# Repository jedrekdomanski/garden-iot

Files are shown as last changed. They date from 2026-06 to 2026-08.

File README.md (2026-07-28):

# 🌱 Garden IoT — Automated Irrigation System

An ESP32-based automated garden irrigation system that measures soil moisture, controls a water pump, and streams telemetry to AWS with real-time visualization via Grafana Cloud.

## Motivation

The idea behind this project was simple — being able to travel, go on holidays, or simply leave home for a day or two without worrying that the vegetables and herbs would die. Instead of relying on someone to water the plants or coming back to a dried-out garden, the system takes care of it automatically. It monitors soil moisture around the clock and waters only when needed, while giving full visibility into what's happening remotely through the Grafana dashboard.

The garden is also planned to grow over time — more plants, more zones, more automation. The system is designed with that in mind, making it easy to extend with additional sensors and devices as the garden expands.

## How it works

The ESP32 is a low-cost, low-power microcontroller with built-in WiFi and Bluetooth, widely used in IoT projects. It features a dual-core 240MHz processor, 520KB of RAM, and a deep sleep mode that draws only ~10µA — making it ideal for battery-powered or solar-powered applications. In this project it runs Arduino firmware compiled with PlatformIO and uses its built-in ADC to read the soil moisture sensor.

The ESP32 wakes from deep sleep every hour, measures soil moisture, decides whether to water, reports all events to AWS, then goes back to sleep. The entire active cycle takes only a few seconds, making it extremely power efficient.

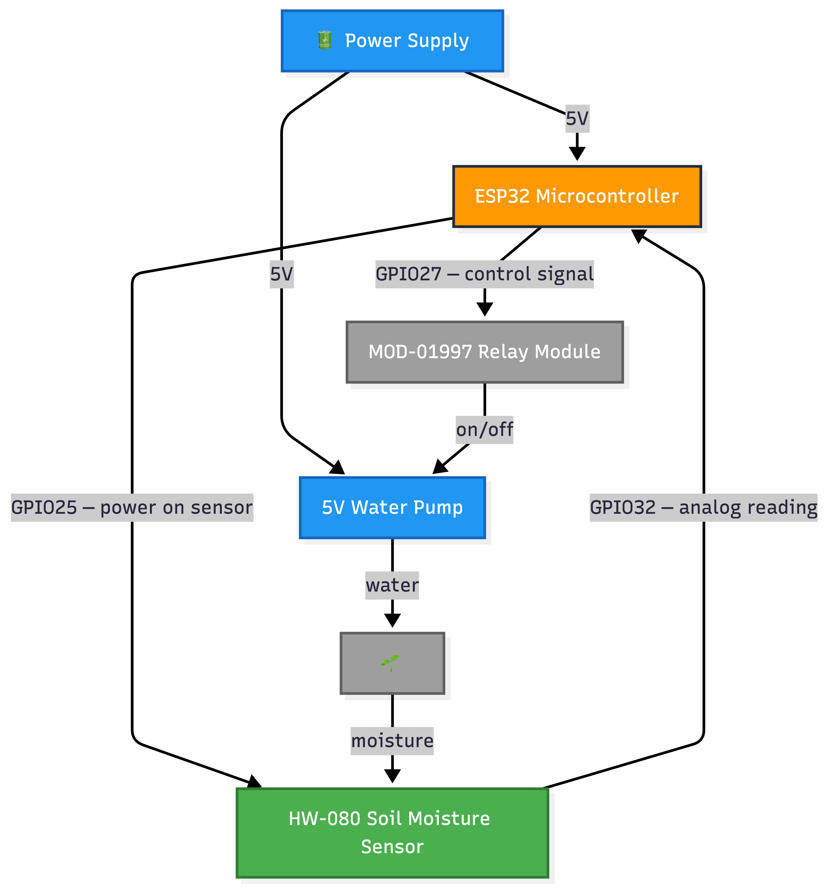
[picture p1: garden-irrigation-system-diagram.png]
Hardware Diagram


### Measurement & watering logic

1. Powers the capacitive soil moisture sensor
2. Takes 10 averaged ADC readings for accuracy
3. Maps the raw value to a 0–100% moisture percentage using calibrated dry/wet values
4. If moisture is below the threshold (60%), triggers the MOSFET transistor to run the water pump for 20 seconds
5. Reports the outcome (`watering_started` / `watering_skipped`) to AWS
6. Goes back to deep sleep for 1 hour

### Events reported

| Event | Description |
|---|---|
| `device_boot` | Device woke up and connected to WiFi |
| `measurement_taken` | Soil moisture reading with raw value and percentage |
| `watering_started` | MOSFET triggered, irrigation started |
| `watering_finished` | MOSFET off, irrigation complete |
| `watering_skipped` | Soil moisture sufficient, watering not needed |
| `device_sleeping` | Device entering deep sleep |

## Hardware

| Component | Details |
|---|---|
| ESP32 DevKit | Dual-core 240MHz, built-in WiFi, deep sleep ~10µA |
| HW-080 Capacitive soil moisture sensor | GPIO 32 (ADC) |
| MOSFET transistor | GPIO 27 — switches power to the water pump |
| Water pump | 12V — controlled via MOSFET transistor |

## AWS Architecture

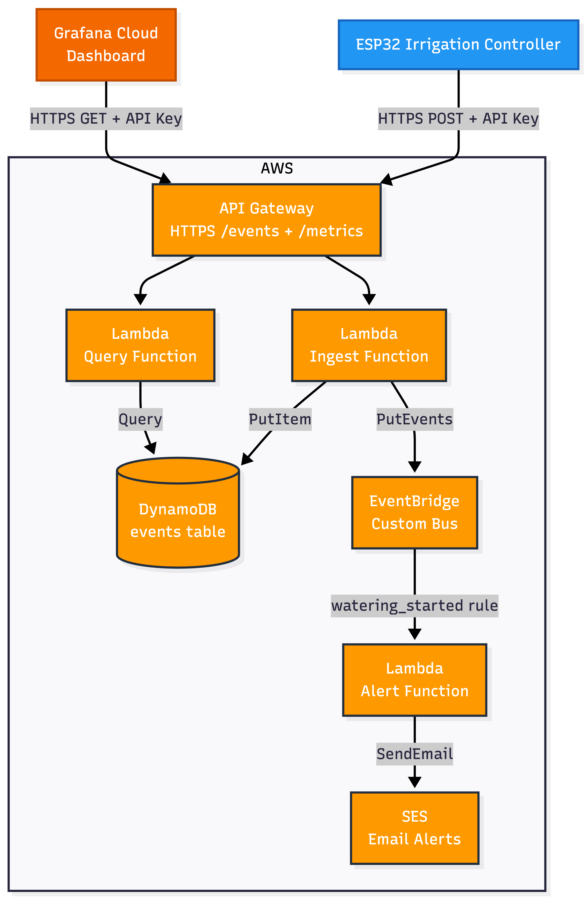
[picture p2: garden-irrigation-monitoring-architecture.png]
System Architecture


### Ingest pipeline
- **API Gateway** — HTTPS endpoint secured with a custom API key authorizer Lambda
- **Ingest Lambda** — validates and writes events to DynamoDB, forwards to EventBridge
- **DynamoDB** — stores all events with a 1-year TTL auto-expiry
- **EventBridge** — routes `measurement_taken` events with moisture < 30% to the alert Lambda
- **SES** — sends email alerts when soil moisture is critically low

### Visualization pipeline
- **Query Lambda** — queries DynamoDB and returns JSON, supports `from`, `to`, and `limit` parameters
- **Grafana Cloud** — polls `GET /metrics` via the Infinity datasource and renders the dashboard

## Grafana Dashboard

Three panels:
- **Current Moisture** — stat panel with color thresholds (green > 45%, yellow > 25%, red below)
- **Soil Moisture** — time series of moisture % over time
- **Event Log** — full table of all device events with timestamps

## Project structure

```
├── firmware/
│   └── garden/
│       ├── src/main.cpp        # ESP32 firmware
│       ├── include/secrets.h   # Generated secrets (git ignored)
│       ├── scripts/load_env.py # Injects .env into build
│       └── platformio.ini
└── terraform/
    ├── lambda/
    │   ├── ingest/handler.py   # Ingest Lambda
    │   ├── query/handler.py    # Query Lambda
    │   ├── authorizer/handler.py
    │   └── alert/handler.py
    ├── api_gateway.tf
    ├── dynamodb.tf
    ├── lambda.tf
    ├── eventbridge.tf
    ├── grafana.tf
    └── ses.tf
```

## Setup

### Prerequisites
- PlatformIO
- Terraform >= 1.6
- AWS CLI with a configured profile
- Grafana Cloud account (free tier)

### Firmware

1. Copy `firmware/.env.example` to `firmware/.env` and fill in your WiFi credentials and API endpoint
2. Build and flash with PlatformIO:
```bash
cd firmware/garden
pio run --target upload
```

### Infrastructure

1. Copy `terraform/terraform.tfvars.example` to `terraform/terraform.tfvars` and set your alert email
2. Deploy:
```bash
cd terraform
terraform init
terraform apply
```
3. Get your API endpoint and key:
```bash
terraform output api_endpoint
terraform output -raw api_key
```

### Grafana Cloud

1. Install the **Infinity** datasource plugin
2. Add a new Infinity datasource with header `x-api-key` set to your API key and allowed host set to your API Gateway domain
3. Create panels using `GET https://<api-endpoint>/metrics` as the data source URL

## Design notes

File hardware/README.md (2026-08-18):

# 🔌 Garden Irrigation System — PCB Hardware

A custom-designed PCB built around the ESP32 DevKit V1, created as part of my personal journey into electronics, IoT, and robotics. The board was designed in **KiCad 10** after several weeks of self-taught KiCad and electronics study.

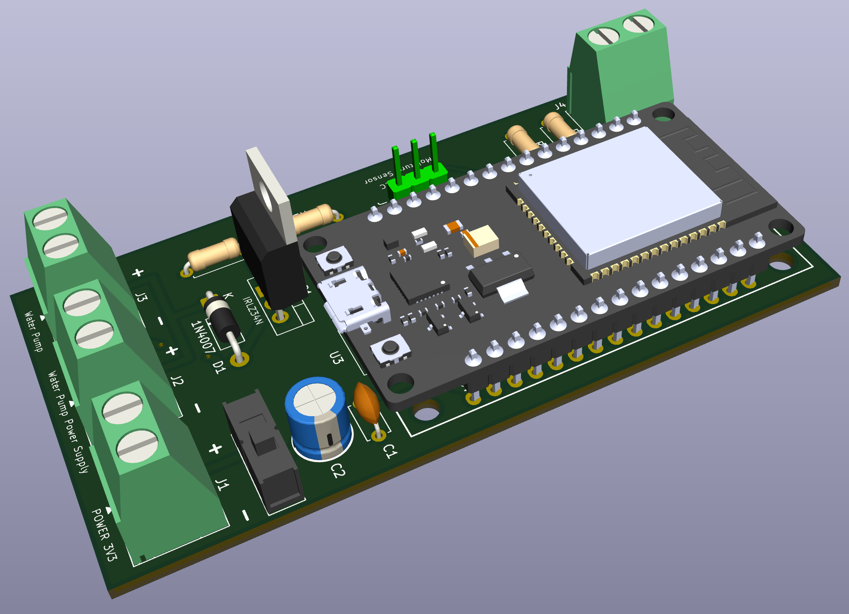
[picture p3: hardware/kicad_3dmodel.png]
PCB 3D Model


## Overview

The board's primary purpose is to control a 12V water pump via a MOSFET transistor, as part of the automated garden irrigation system. It integrates power management monitoring, soil moisture sensing, pump control, and a safe programming switch into a single compact board.

## Features

### Soil Moisture Sensing
The board interfaces with a capacitive soil moisture sensor (HW-080) connected to the ESP32's ADC. The sensor provides real-time soil moisture readings that the microcontroller uses to decide whether to activate the water pump. If moisture drops below the configured threshold, the pump is triggered automatically.

### Pump Control via MOSFET
The water pump is switched on and off by a MOSFET transistor (1N4007 flyback diode included for protection against voltage spikes from the inductive pump load). The ESP32 drives the MOSFET gate directly from a GPIO pin.

### Power Supply
The ESP32 and board logic are powered by a custom-designed 3.3V solar-powered power management module:

👉 [Solar-Powered 3.3V Power Management PCB](https://github.com/jedrekdomanski/solar-charger-pcb)

The board includes battery voltage monitoring, allowing the firmware to track the power module's battery level.

### USB Programming Switch
A slide switch allows safe switching between two modes:

- **3.3V power on** — normal operation, powered by the power management module
- **3.3V power off + USB connected** — firmware upload mode

When flashing a firmware update, the workflow is:
1. Flip the slide switch to cut the 3.3V supply
2. Connect the USB cable to the ESP32
3. Upload the firmware via PlatformIO
4. Disconnect USB, flip the switch back to restore 3.3V power

This prevents conflicts between the USB power rail and the external 3.3V supply during programming.

## Components

| Component | Details |
|---|---|
| ESP32 DevKit V1 | Main microcontroller — WiFi, deep sleep, ADC |
| HW-080 capacitive soil moisture sensor | GPIO 32 (ADC) — triggers pump when moisture is too low |
| MOSFET transistor | Controls the 12V water pump via GPIO 27 |
| 1N4007 diode | Flyback protection for the pump |
| Slide switch | Isolates 3.3V supply during USB programming |
| Power management module | Custom 3.3V solar-powered PCB (see link above) |

## Design

Designed in **KiCad 10** — schematic and PCB layout files are located in this directory:

- `ESP32_Irrigation_system.kicad_sch` — schematic
- `ESP32_Irrigation_system.kicad_pcb` — PCB layout
- `ESP32_Irrigation_system.kicad_pro` — project file

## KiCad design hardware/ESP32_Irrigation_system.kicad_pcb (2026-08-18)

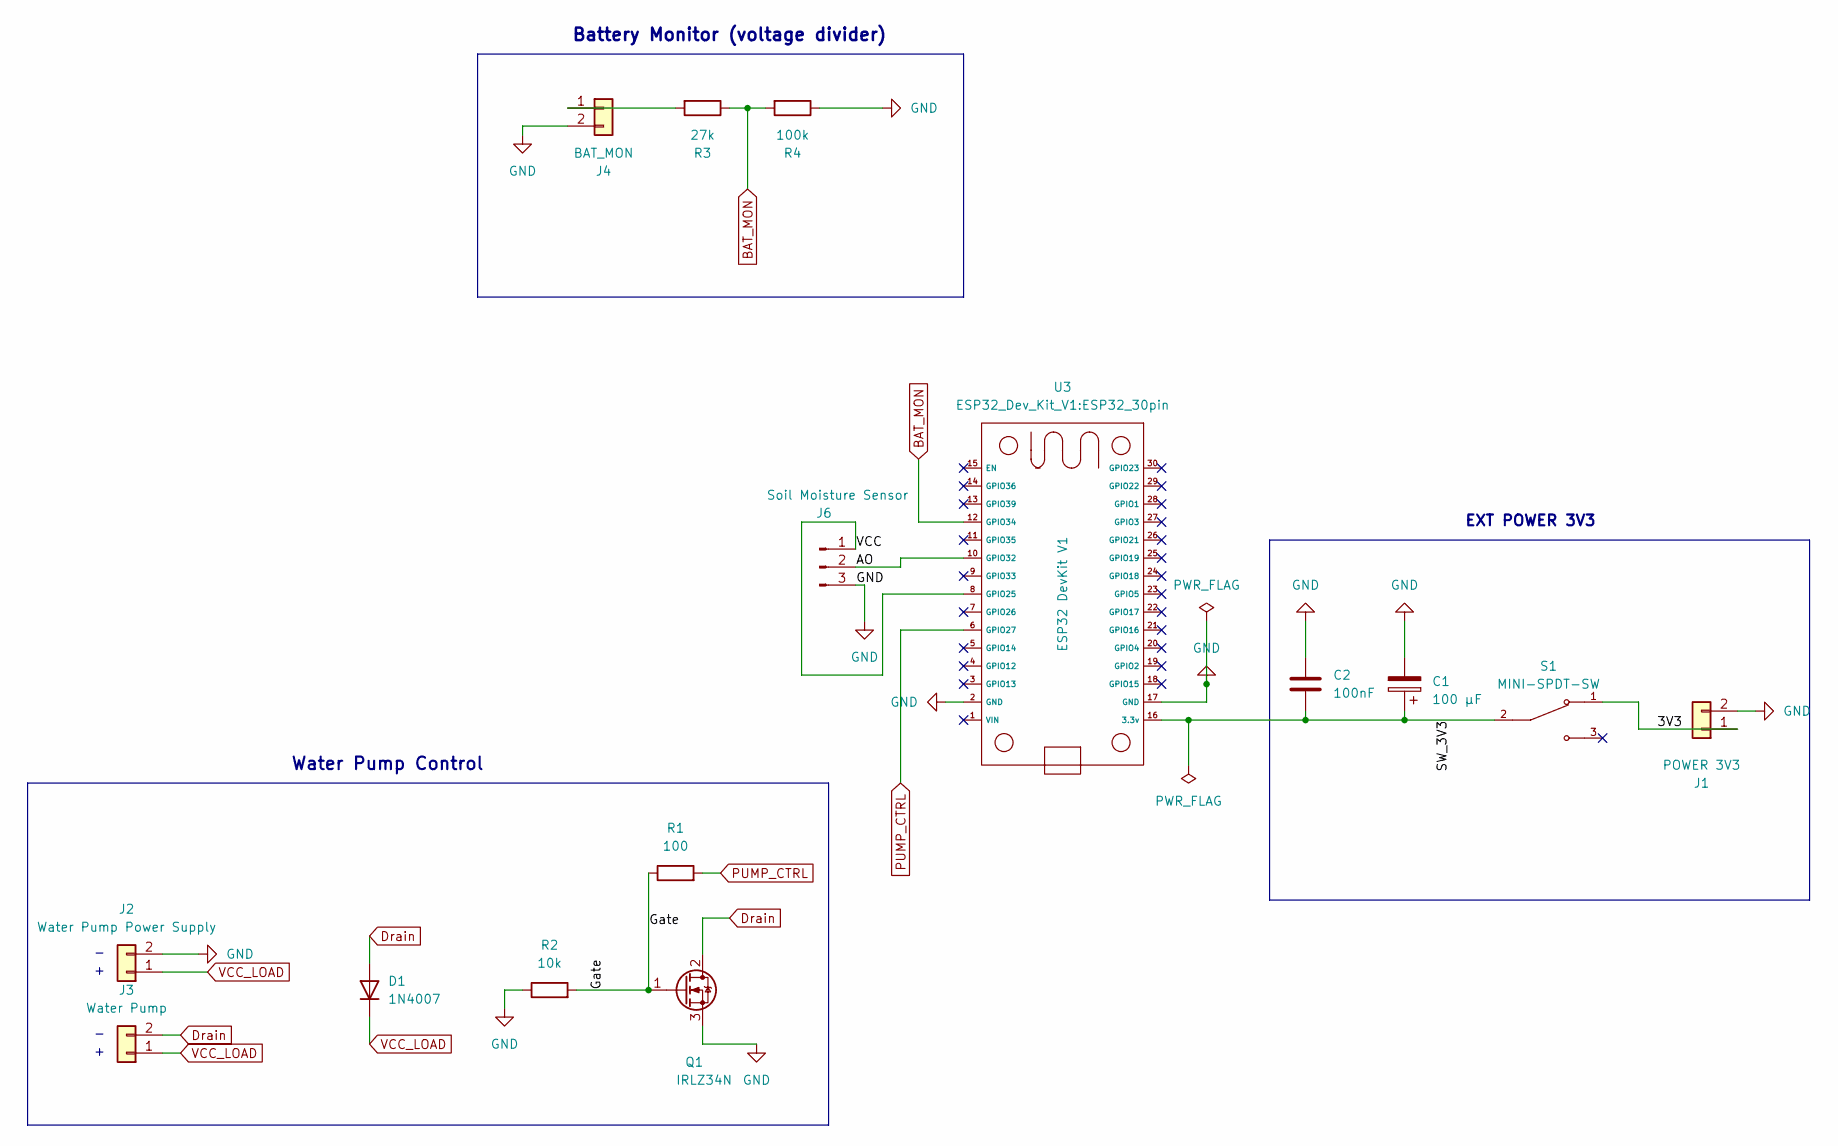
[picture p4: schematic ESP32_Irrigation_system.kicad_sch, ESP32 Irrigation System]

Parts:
C1: ‬‭‬‭‬‭‬‬‭‬‭‬‭‬‬‭‬‭‬‭‬100 μF; CP_Radial_D6.3mm_P2.50mm
C2: 100nF; C_Disc_D5.0mm_W2.5mm_P5.00mm
D1: 1N4007; D_DO-41_SOD81_P10.16mm_Horizontal
J1: POWER 3V3; TerminalBlock_Phoenix_MKDS-1,5-2-5.08_1x02_P5.08mm_Horizont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
J2: Water Pump Power Supply; TerminalBlock_Phoenix_MKDS-1,5-2-5.08_1x02_P5.08mm_Horizont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
J3: Water Pump; TerminalBlock_Phoenix_MKDS-1,5-2-5.08_1x02_P5.08mm_Horizont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
J4: BAT_MON; TerminalBlock_Phoenix_MKDS-1,5-2-5.08_1x02_P5.08mm_Horizont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
J6: Soil Moisture Sensor; PinHeader_1x03_P2.54mm_Vertical
Q1: IRLZ34N; TO-220-3_Vertical
R1: 100; R_Axial_DIN0207_L6.3mm_D2.5mm_P7.62mm_Horizontal
R2: 10k; R_Axial_DIN0207_L6.3mm_D2.5mm_P7.62mm_Horizontal
R3: 27k; R_Axial_DIN0207_L6.3mm_D2.5mm_P7.62mm_Horizontal
R4: 100k; R_Axial_DIN0207_L6.3mm_D2.5mm_P7.62mm_Horizontal
S1: MINI-SPDT-SW; SW_MINI-SPDT-SW; PARTREV C
U3: ESP32 DevKit V1; ESP32_30pin

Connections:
/3V3: J1.1, S1.1
/AO: J6.2, U3.10 (GPIO32)
/Gate: Q1.1 (G), R1.1, R2.2
/SW_3V3: C1.1, C2.2, S1.2, U3.16 (3.3v)
/VCC: J6.1, U3.8 (GPIO25)
BAT_MON: R3.1, R4.2, U3.12 (GPIO34)
Drain: D1.2 (A), J3.2, Q1.2 (D)
GND: C1.2, C2.1, J1.2, J2.2, J4.2, J6.3, Q1.3 (S), R2.1, R4.1, U3.2 (GND), U3.17 (GND)
unnamed: J4.1, R3.2
PUMP_CTRL: R1.2, U3.6 (GPIO27)
VCC_LOAD: D1.1 (K), J2.1, J3.1

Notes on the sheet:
EXT POWER 3V3
Water Pump Control
Battery Monitor (voltage divider)

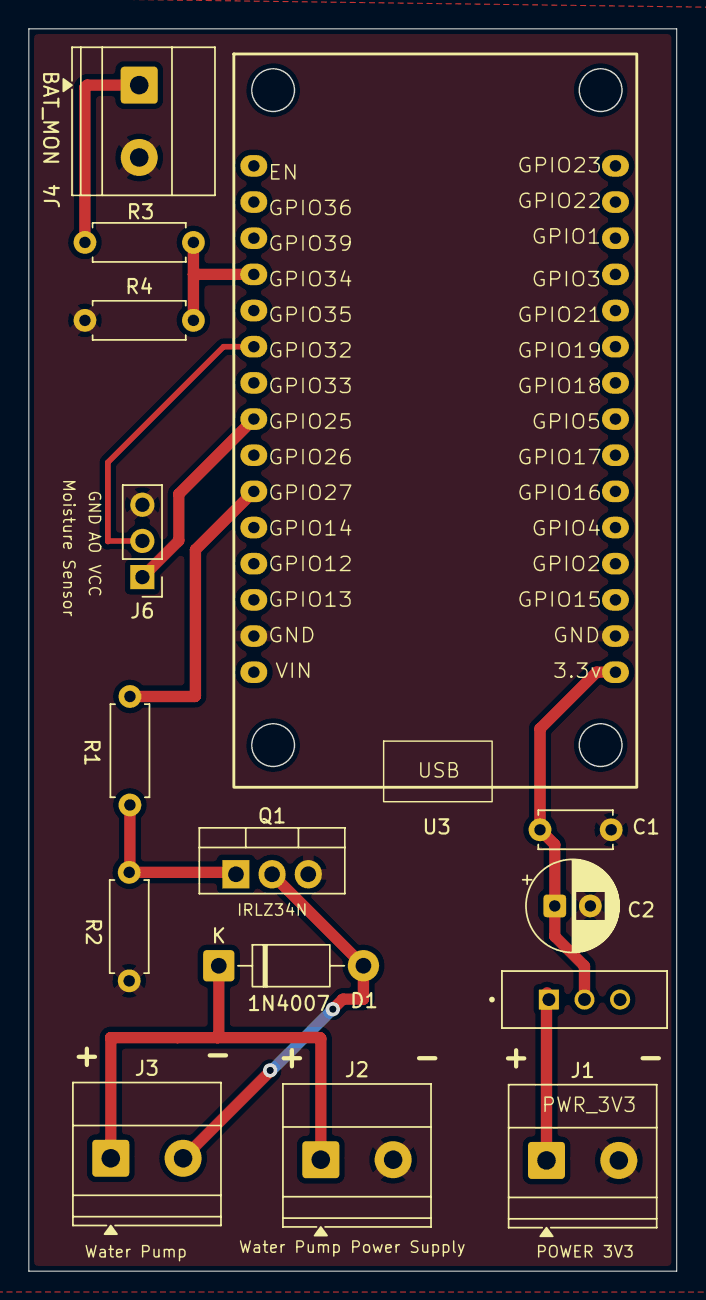
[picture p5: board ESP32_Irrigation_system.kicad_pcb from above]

Board: 2 copper layers, 45.5 x 87.3 mm, 15 parts (0 on the bottom side), 11 nets.

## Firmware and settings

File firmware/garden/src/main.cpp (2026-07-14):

#define SENSOR_POWER 25
#define SENSOR_PIN   32
#define RELAY_PIN    27

#include <WiFi.h>
#include <HTTPClient.h>
#include <time.h>
#include <secrets.h>

// --- Calibration ---
const int DRY_VALUE          = 4095;
const int WET_VALUE          = 980;
const int MOISTURE_THRESHOLD = 60;

void connectWifi() {
  WiFi.begin(WIFI_SSID, WIFI_PASSWORD);
  Serial.print("Connecting to WiFi");
  while (WiFi.status() != WL_CONNECTED) {
    delay(500);
    Serial.print(".");
  }
  Serial.println("\nWiFi connected, IP: " + WiFi.localIP().toString());
}

bool syncTime() {
  configTzTime("CET-1CEST,M3.5.0/2,M10.5.0/3", "pool.ntp.org", "time.google.com");
  struct tm timeinfo;
  for (int i = 0; i < 20; i++) {
    if (getLocalTime(&timeinfo, 500)) {
      Serial.println("Time synced");
      return true;
    }
    delay(250);
  }
  Serial.println("Time sync failed");
  return false;
}

String getDateString() {
  struct tm timeinfo;
  if (!getLocalTime(&timeinfo, 500)) return "unknown";
  char buf[11];
  strftime(buf, sizeof(buf), "%d-%m-%Y", &timeinfo);
  return String(buf);
}

String getTimeString() {
  struct tm timeinfo;
  if (!getLocalTime(&timeinfo, 500)) return "unknown";
  char buf[6];
  strftime(buf, sizeof(buf), "%H:%M", &timeinfo);
  return String(buf);
}

String buildEvent(const String& eventName, const String& extraJson = "") {
  String p = "{\"source\":\"esp32\",\"date\":\"" + getDateString() +
             "\",\"time\":\"" + getTimeString() +
             "\",\"event\":\"" + eventName + "\"";
  if (extraJson.length() > 0) p += "," + extraJson;
  p += "}";
  return p;
}

void publishEvent(const String& payload) {
  HTTPClient http;
  http.begin(API_ENDPOINT);
  http.addHeader("Content-Type", "application/json");
  http.addHeader("x-api-key", API_KEY);

  int statusCode = http.POST(payload);
  Serial.print("POST " + payload + " -> HTTP ");
  Serial.println(statusCode);

  http.end();
}

void setup() {
  Serial.begin(115200);
  delay(2000);  // allow Serial Monitor to reconnect after deep sleep wake

  pinMode(SENSOR_POWER, OUTPUT);
  pinMode(RELAY_PIN, OUTPUT);
  digitalWrite(RELAY_PIN, HIGH);

  connectWifi();
  syncTime();

  publishEvent(buildEvent("device_boot"));

  // --- Measure ---
  digitalWrite(SENSOR_POWER, HIGH);
  delay(2000);

  long sum = 0;
  for (int i = 0; i < 10; i++) {
    sum += analogRead(SENSOR_PIN);
    delay(30);
  }
  int rawValue = sum / 10;

  int moisturePercent = map(rawValue, DRY_VALUE, WET_VALUE, 0, 100);
  moisturePercent = constrain(moisturePercent, 0, 100);

  Serial.printf("Raw: %d  Moisture: %d%%\n", rawValue, moisturePercent);

  publishEvent(buildEvent(
    "measurement_taken",
    "\"raw_value\":" + String(rawValue) + ",\"moisture_percent\":" + String(moisturePercent)
  ));

  digitalWrite(SENSOR_POWER, LOW);

  // --- Water or skip ---
  if (moisturePercent <= MOISTURE_THRESHOLD) {
    publishEvent(buildEvent(
      "watering_started",
      "\"moisture_percent\":" + String(moisturePercent) + ",\"threshold\":" + String(MOISTURE_THRESHOLD)
    ));

    digitalWrite(RELAY_PIN, LOW);
    delay(30000);
    digitalWrite(RELAY_PIN, HIGH);

    publishEvent(buildEvent("watering_finished", "\"duration_seconds\":20"));
  } else {
    publishEvent(buildEvent(
      "watering_skipped",
      "\"reason\":\"soil_ok\",\"moisture_percent\":" + String(moisturePercent)
    ));
  }

  // --- Sleep ---
  publishEvent(buildEvent("device_sleeping", "\"sleep_seconds\":3600"));

  WiFi.disconnect(true);
  esp_sleep_enable_timer_wakeup(3600ULL * 1000000ULL);
  esp_deep_sleep_start();
}

void loop() {}

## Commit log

2026-07-13 Update readme and elongate water pump delay (#8)
2026-07-28 replace relay module with MOSFET (#11)
2026-08-18 Add KiCAD project (#12)
    [ESP32_Irrigation_system.kicad_pcb, ESP32_Irrigation_system.kicad_sch]
